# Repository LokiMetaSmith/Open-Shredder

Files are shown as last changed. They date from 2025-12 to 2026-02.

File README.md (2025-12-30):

# Open-Shredder
OpenShredder is a general purpose 3D printable shredder designed for recycling plastic

The goal of this project is to democratize the knowledge and empower individuals to remove plastics from their community waste stream and transform them through the below described processes into long lived, durable goods that can again be recycled at the end of their usefulness. 

# Scope of Work

Initially, non-uniform plastic objects need to be mechanically broken down into a uniform format that can be processed into new products. This first process requires a shredder, which is a machine that mechanically breaks plastic down into uniform pieces of a desired size.

The shredder needs to be relatively quiet and be able to handle the recyclable plastic seen in modern society. 
| Plastic #  |Abbr. |Description |
|---|---|---|
| Recycle #1 | PET  | polyethylene terephthalate | 
| Recycle #2 | HDPE | polyethylene, high density | 
| Recycle #3 | PVC  | poly(vinyl chloride) | 
| Recycle #4 | LDPE | polyethylene, low density  | 
| Recycle #5 | PP | polypropylene | 

Plastics can have fillers, contamination, or be damaged from UV, thermal, or mechanical stress that change their initial properties. In these cases, mixing in additive plastics can help mitigate the damage and restore some of the materials initial properties. Additive plastics can be freshly manufactured plastic or plastics with complementary properties. We're investigating if https://docs.plasticscanner.com/ can be used to fill this need.

On the market, there are several commercial shredder options designed for dedicated spaces and high volume plastic shredding. Unfortunately, these machines and techniques do not meet the above goal of being usable by a single individual. A cooperative community recycling center would be ideal for one of these high volume machines.

The best documented and supported DIY plastic shredder would be the Precious Plastics Shredder. However, the current bill of materials (BOM) lists the price as $2,234.17, which is an amazing 5x lower price difference from commercial shredders and is competitive with equivalent commercial shredders from Asian markets. This doesn’t include labor and overhead plus reinvestment profits. 

# Objective

To realize a further reduction of price and complexity, a shredder designed from the ground up to be sustainable and accessible needs to be developed. By designing mechanical components capable of being made on a 3D printer, we potentially can use the very plastic material shredded in the creation of new shredders, as well as expand the list of useful machines buildable with a 3D printer. When considering a shredder built of plastic designed to shred plastic, we will both need to create a community, collaborate with an existing community, or reinvigorate an inactive community as it is unlikely that our initial efforts will be sufficient to solve low cost waste processing. Community activity can’t only be limited to technical work. Cultural and social norms around recycling need to be addressed and both trust and accountability need to be earned. We can leverage an Open Source Hardware project and a call to action, along with organizational resources such as documentation management, official builds, development resources, and coordination of efforts. 

Currently the design of the shredder is thought to be a single shaft shredder, which is a simple but robust design that uses a pusher lever to feed material against rotating knives along a single stationary blade. A screen acts as a filter to only let material of a certain shape through. These machines use low speed, high torque gearboxes to process a high variety of materials. 

To accomplish this with a 3D printed shredder, it is envisioned that the central shaft will be 3D printed and like with commercial units, steel or carbide inserts will make up the cutting knife edges, and plastic will provide backing and support. To provide high torque, a cycloidal gearbox will be coupled to the shaft on both sides to provide support and the required force. 

Future work includes using the shredded material in a variety of applications, some of which are demonstrated by Precious Plastics, such as building materials and consumer goods. A further goal would be to use the shredded plastic for 3D printing as either feed stock for a filament extruder or directly with a pellet extruder 3D printing head. 

# Project Outline

## Tools Used
SPEC will develop an easily installable web hosted Jupyter notebook and docker container that has all the tools nessisary to contribute to this project. 

CadQuery is a parametric 3D Computer Aided Design (CAD) language and software library, written in Python, that allows for expressive 3D designs to be modeled and assembeled virtually. 

CadQuery: https://github.com/CadQuery/cadquery

Jupyter-CadQuery, combines the utility of Jupyter notebooks, with 3D cad drawings produced with CadQuery. It also allows for live code and deploy environments, and many more features. 

Jupiter-CadQuery: https://github.com/bernhard-42/jupyter-cadquery

## Proof of Concept

  The first proof of concept, will utilize a fully parametrized 3D printed shredder drum

## First Release

## Rolling Release Schedule

## Production and Manufacturing

## Call for Collaboration: Open Problems

  The project would benefit from a mechanical engineer or an expert 3D modeler, as the component geometries are getting complex. Also, the prime power drive is non obvious. Most commercial shredders use high speed, low torque electric AC motors with a gear reduction mechanism, which both increase cost and are non-standard. A creative solution would utilize the impact resistance of certain plastics to incorporate a fly wheel impact driver mechanism to increase the total torque output of the device. It is believed that doing so will allow for an almost completely 3D printed shredder. 

# Motor Selection

After reviewing the project requirements for a home-friendly, quiet, and 3D-printable capable shredder, we have selected the **NEMA 34 Stepper Motor** as the prime mover.

### Reasons for Selection:
1.  **High Torque:** NEMA 34 motors offer significantly higher holding torque (often 4-12 Nm) compared to NEMA 23, which is crucial for shredding solid chunks of plastic.
2.  **Quiet Operation:** Unlike universal AC motors or gearbox-driven DC motors, stepper motors run relatively quietly, making them suitable for home environments.
3.  **Direct Compatibility with Printed Gearbox:** The low speed of the stepper (typically <1000 RPM useful range) matches well with a single-stage cycloidal reduction (10:1 to 20:1) without requiring complex multi-stage gearing.
4.  **Future Proofing:** The NEMA 34 mounting standard is a common target for "3D Printed Brushless Motor" projects. By designing the gearbox for a NEMA 34 interface, this shredder can easily be upgraded to a DIY printable motor in the future.

### Configuration
- **Mounting Hole Spacing:** 69.6 mm
- **Shaft Diameter:** 14.0 mm
- **Driver:** A high-voltage (AC powered or 60V+ DC) stepper driver (e.g., DM860T) is recommended to maximize torque at speed.

### Alternative Option: Windshield Wiper Motor
For a low-cost, high-torque salvage option, the gearbox also supports a **Generic Wiper Motor** pattern.
- **Mounting:** 3-Bolt pattern (approx 2" / 50.8mm bolt circle).
- **Configuration:** Set `motor_type="WIPER"` in the assembly script.
- **Note:** Requires a high-current 12V DC power supply (e.g., PC PSU or Car Battery). Mounting holes may need slotting for specific motor variations.

# Cycloidal Generators:
https://github.com/RepRapLtd/RobotComponents/tree/main/RRL-cycloidal-drive
https://github.com/mawildoer/cycloidal_generator
https://github.com/mikedh/cycloidal
https://hackaday.io/project/168498-opencyre

## Related Projects
https://github.com/CubeFactory2/cubefactory
https://plasticscanner.com/

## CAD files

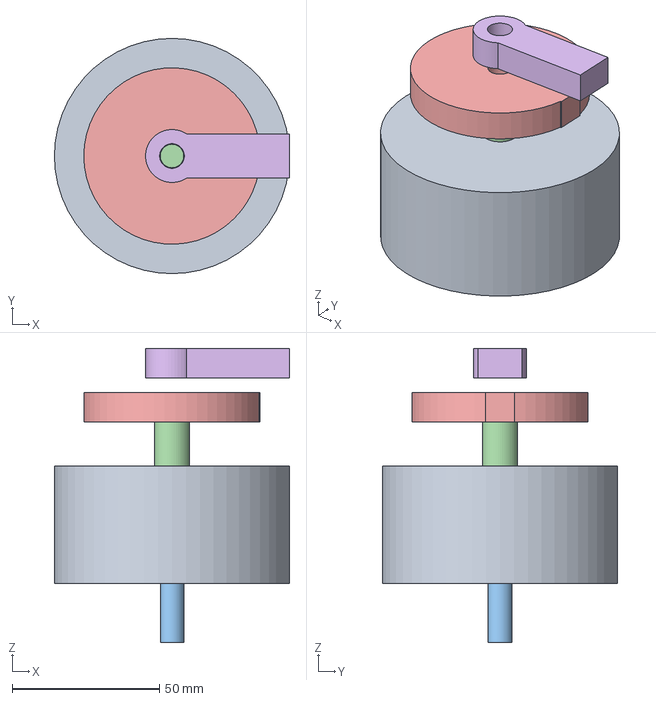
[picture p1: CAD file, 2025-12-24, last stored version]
shredder_gearbox_assembly.step
80.0 x 80.0 x 100.0 mm

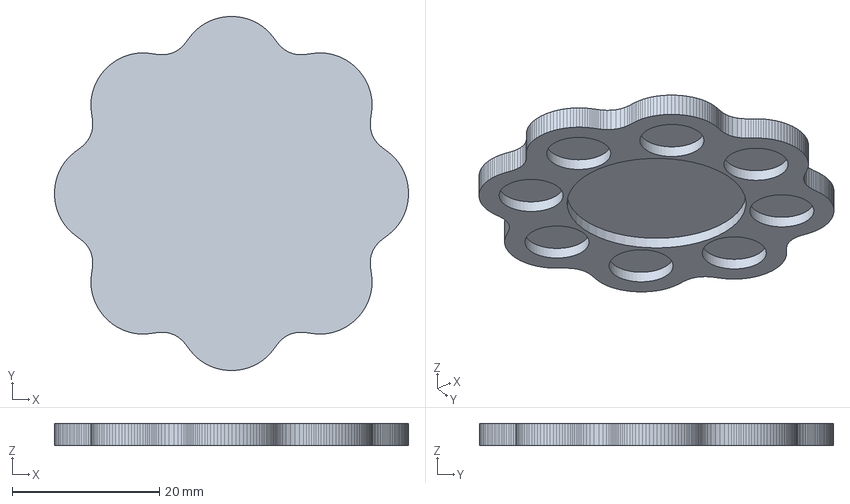
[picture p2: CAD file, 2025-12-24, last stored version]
cycloidal_disk.step
48.0 x 48.0 x 3.00 mm

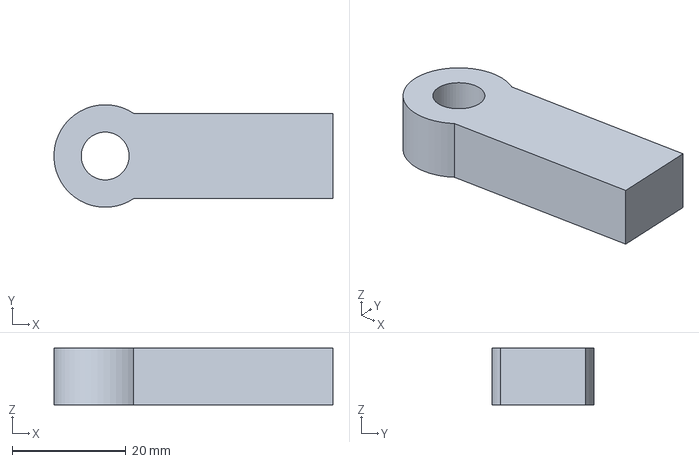
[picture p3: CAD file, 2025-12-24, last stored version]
impact_hammer.step
49.0 x 18.0 x 10.0 mm

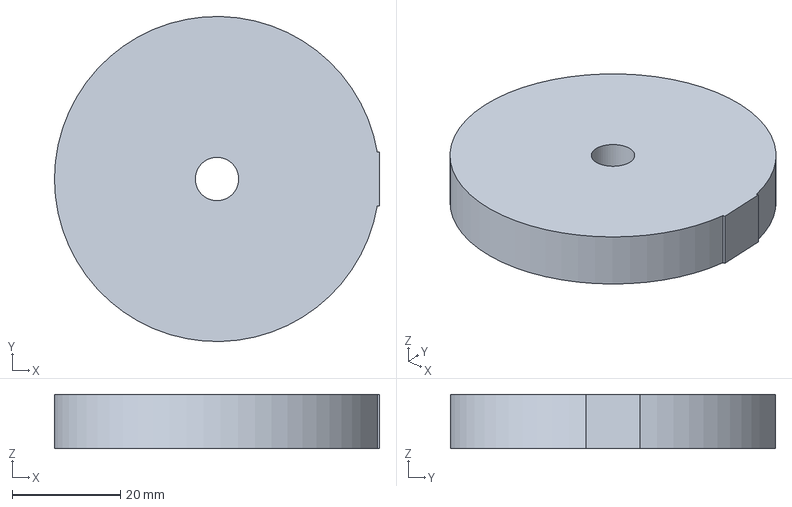
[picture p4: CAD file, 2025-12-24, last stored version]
slip_disk.step
60.0 x 60.0 x 10.0 mm

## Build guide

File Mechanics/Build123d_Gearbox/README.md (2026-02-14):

# OpenShredder Gearbox & Components (Build123d)

This directory contains Python scripts to generate the 3D models for the OpenShredder gearbox and shredder mechanism using [build123d](https://github.com/gumyr/build123d).

## Prerequisites

You need `build123d` and `scikit-fem` installed:
```bash
pip install build123d scikit-fem meshio numpy scipy
```

## Parameter Configuration

All design parameters are centralized in `parameters/shredder_config.json`.
You can modify this file directly, or use the Optimization Agent to tune it.

## New Workflow: Validation & Optimization

We have implemented an AI-driven optimization loop to ensure the design is mechanically sound.

### 1. Validate Design
Checks geometric constraints (e.g., shaft fit) and mechanical feasibility (torque).
```bash
python3 validate_design.py
```

### 2. Simulate Stress
Runs a Finite Element Analysis (FEA) or analytical simulation to calculate shaft stress and safety factors.
```bash
python3 simulate_stress.py
```

### 3. Optimize Design (Agent)
An intelligent agent that iteratively tweaks parameters (Gear Ratio, Shaft Size, Drum Diameter) to maximize throughput while satisfying safety constraints.
```bash
python3 optimize_design.py
```
This will generate `parameters/optimized_shredder_config.json`.

## Generating Models

The generation scripts automatically load `parameters/optimized_shredder_config.json` if it exists, otherwise they use `parameters/shredder_config.json`.

### Full Assembly
Generates the complete machine model (Gearbox + Shredder + Pusher).
```bash
python3 full_machine_assembly.py
```
- Output: `open_shredder_full_assembly.step`

### Individual Components

- **Gearbox:** `python3 gearbox_assembly.py` -> `shredder_gearbox_assembly.step`
- **Shredder Parts:** `python3 shredder_components.py`
- **Pusher:** `python3 pusher_mechanism.py`

## Scripts Overview

- `parameters/shredder_config.py`: Configuration schema.
- `validate_design.py`: Validation logic.
- `simulate_stress.py`: FEA/Analytical simulation logic.
- `optimize_design.py`: Optimization agent.
- `cycloidal_gear.py`: Generates the core cycloidal disk.
- `impact_drive.py`: Generates the slip-disk and impact hammer mechanism.
- `shredder_components.py`: Generates internal shredder parts.
- `gearbox_assembly.py`: Generates gearbox assembly.
- `full_machine_assembly.py`: Generates full machine assembly.

## Configuration
Adjust parameters in `parameters/shredder_config.json` manually or use `optimize_design.py`.

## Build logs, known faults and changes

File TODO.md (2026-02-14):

# OpenShredder Project Roadmap

This document tracks the ongoing development, optimization, and future feature requests for the OpenShredder project.

## 1. Mechanical Design (Build123d)

### Completed
- [x] **Parametric Gearbox:** Centralized configuration (`shredder_config.json`) for gear ratio, housing dimensions, and shaft sizes.
- [x] **End-to-End Validation:** Script (`validate_design.py`) to check geometric fit and torque requirements.
- [x] **Stress Simulation:** FEA-based torsion simulation (`simulate_stress.py`) for the hexagonal output shaft.
- [x] **Design Optimization Agent:** Automated script (`optimize_design.py`) to tune parameters for maximum throughput/safety.
- [x] **Full Assembly Generation:** `full_machine_assembly.py` generates the complete machine STEP file based on the optimized config.

### In Progress / TODO
- [ ] **Hopper Design:** The current `pusher_mechanism.py` is a placeholder. A full hopper with guide rails is needed.
- [ ] **Bearing Integration:** Explicitly model bearing pockets and select standard bearings (e.g., 6000 series) in the configuration.
- [ ] **Helical Gear Profile:** The current cycloidal drive uses straight pins. Evaluate helical or double-cycloid for smoother operation/noise reduction.
- [ ] **Fastener Library:** Add bolts, nuts, and washers to the assembly script for a complete BOM.
- [ ] **Frame/Stand:** Design a parametric frame (aluminum extrusion or welded steel) to mount the gearbox and motor.

## 2. Simulation & Analysis

### Completed
- [x] **Torsion FEA:** 2D Poisson solver for hexagonal shaft torsion.

### In Progress / TODO
- [ ] **Bending Moment Analysis:** The shaft also experiences bending from the shredding force. Update `simulate_stress.py` to include bending + torsion (Von Mises stress).
- [ ] **Tooth Strength Analysis:** Simulate the stress on the shredder teeth/inserts to prevent fracture.
- [ ] **Jamming Simulation:** Create a dynamic simulation (time-stepped) to model potential jam scenarios and test the "Impact Drive" effectiveness.
- [ ] **Thermal Analysis:** Estimate heat generation in the gearbox/motor for continuous duty cycles.

## 3. Firmware (Arduino Motor Controller)

### Completed
- [x] **Basic Motor Control:** Stepper and DC motor support.
- [x] **Jam Detection:** Current monitoring and auto-reverse logic.

### In Progress / TODO
- [ ] **Load-Dependent Speed Control:** Automatically reduce speed (increase torque) when current spikes, before a full jam occurs.
- [ ] **Impact Mode Tuning:** Refine the "back-off and strike" algorithm parameters based on real-world testing.
- [ ] **User Interface:** Add a simple LCD/OLED menu to configure settings (e.g., reverse time, current limit) without reflashing.
- [ ] **Telemetry:** Output real-time current/RPM data to serial for analysis/digital twin verification.

## 4. Documentation

### Completed
- [x] **Workflow Documentation:** Updated `Mechanics/Build123d_Gearbox/README.md` with new validation/optimization steps.

### In Progress / TODO
- [ ] **Assembly Manual:** Step-by-step PDF or Wiki for assembling the physical hardware.
- [x] **Bill of Materials (BOM):** Auto-generate a CSV BOM from the python scripts (`generate_bom.py`).
- [ ] **Tuning Guide:** Instructions on how to interpret validation errors and manually tune the `shredder_config.json`.

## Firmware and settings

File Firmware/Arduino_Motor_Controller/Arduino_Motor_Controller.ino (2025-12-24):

#include "DCDriver.h"
#include "StepperDriver.h"
#include "ShredderController.h"

// ================= USER CONFIGURATION =================

// Select Motor Type: 1 = DC, 2 = STEPPER
#define MOTOR_TYPE 1

// --- Pins for DC Motor ---
#define PIN_DC_PWM      3
#define PIN_DC_DIR      4
#define PIN_DC_CURRENT  A0

// --- Pins for Stepper Motor ---
#define PIN_STEP_PUL    3
#define PIN_STEP_DIR    4
#define PIN_STEP_ENA    5
#define PIN_STEP_ALARM  6

// --- Logic Settings ---
#define CURRENT_LIMIT   800   // 0-1023 ADC
#define USE_IMPACT_MODE true  // Enable Impact Hammer logic

// ======================================================

MotorInterface* driver = nullptr;
ShredderController* controller = nullptr;

void setup() {
    Serial.begin(115200);
    Serial.println("Shredder Controller Starting...");

    // Initialize Driver
    #if MOTOR_TYPE == 1
        driver = new DCDriver(PIN_DC_PWM, PIN_DC_DIR, PIN_DC_CURRENT);
        Serial.println("Mode: DC Motor");
    #elif MOTOR_TYPE == 2
        driver = new StepperDriver(PIN_STEP_PUL, PIN_STEP_DIR, PIN_STEP_ENA, PIN_STEP_ALARM);
        Serial.println("Mode: Stepper Motor");
    #endif

    driver->begin();

    // Initialize Controller
    controller = new ShredderController(driver);

    ShredderConfig config;
    config.forwardSpeed = 100; // 100%
    config.reverseSpeed = 60;
    config.currentLimit = CURRENT_LIMIT;
    config.runDuration = 0; // Infinite
    config.useImpactMode = USE_IMPACT_MODE;

    controller->setConfig(config);

    // Start Sequence
    controller->start();
    Serial.println("Controller Started.");
}

void loop() {
    // Main update loop
    if (controller) {
        controller->update();

        // Optional: Print Status periodically
        static unsigned long lastPrint = 0;
        if (millis() - lastPrint > 1000) {
            lastPrint = millis();
            Serial.print("State: ");
            Serial.print(controller->getState());
            Serial.print(" Load: ");
            Serial.println(driver->getLoad());
        }
    }
}

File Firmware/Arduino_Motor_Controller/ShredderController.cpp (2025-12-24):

#include "ShredderController.h"

#ifdef ARDUINO
    #include <Arduino.h>
#else
    #include "../tests/mock_arduino.h"
#endif

ShredderController::ShredderController(MotorInterface* motor) {
    _motor = motor;
    _state = STATE_IDLE;
    _jamCount = 0;

    // Defaults
    _config.forwardSpeed = 100;
    _config.reverseSpeed = 50;
    _config.currentLimit = 800;
    _config.runDuration = 0;
    _config.reverseDuration = 2000;
    _config.useImpactMode = false;
    _config.impactBackoffDuration = 1000;
}

void ShredderController::setConfig(ShredderConfig config) {
    _config = config;
}

void ShredderController::start() {
    _state = STATE_FORWARD;
    _stateStartTime = millis();
    _runStartTime = millis();
    _motor->setSpeed(_config.forwardSpeed);
    _jamCount = 0;
}

void ShredderController::stop() {
    _state = STATE_IDLE;
    _motor->stop();
}

void ShredderController::update() {
    unsigned long now = millis();
    _motor->update(); // Tick the motor driver

    // State Machine
    switch (_state) {
        case STATE_IDLE:
            // Do nothing
            break;

        case STATE_FORWARD:
            // Check Timeout
            if (_config.runDuration > 0 && (now - _runStartTime > _config.runDuration)) {
                stop();
                return;
            }

            // Inrush Masking: Ignore current spikes during the first 500ms of entering STATE_FORWARD
            if (now - _stateStartTime > 500) {
                // Check Jam/Fault
                if (_motor->getLoad() > _config.currentLimit || _motor->isFaulted()) {
                    _state = STATE_JAM_DETECTED;
                    _stateStartTime = now;
                    _motor->stop();
                    _jamCount++;
                }
            }
            break;

        case STATE_JAM_DETECTED:
            // Pause briefly before reversing to protect electronics
            if (now - _stateStartTime > 500) {
                if (_config.useImpactMode) {
                    // Impact Strategy: Back up, then strike
                    _state = STATE_IMPACT_PREP_BACKOFF;
                    _motor->setSpeed(-_config.reverseSpeed);
                } else {
                    // Standard Strategy: Reverse, then Forward
                    _state = STATE_REVERSE_CLEARING;
                    _motor->setSpeed(-_config.reverseSpeed);
                }
                _stateStartTime = now;
            }
            break;

        case STATE_REVERSE_CLEARING:
            if (now - _stateStartTime > _config.reverseDuration) {
                _state = STATE_FORWARD;
                _motor->setSpeed(_config.forwardSpeed);
                _stateStartTime = now;
            }
            break;

        case STATE_IMPACT_PREP_BACKOFF:
            // Back up significantly
            if (now - _stateStartTime > _config.impactBackoffDuration) {
                _state = STATE_IMPACT_STRIKE;
                // Full speed forward for maximum inertia
                _motor->setSpeed(100);
                _stateStartTime = now;
            }
            break;

        case STATE_IMPACT_STRIKE:
            // We stay in this mode for a minimum time to ensure we hit the object
            // or we just switch back to FORWARD monitoring immediately?
            // Let's switch to FORWARD after a brief acceleration period
            if (now - _stateStartTime > 500) {
                _state = STATE_FORWARD;
                _motor->setSpeed(_config.forwardSpeed);
                _stateStartTime = now;
            }
            break;

        case STATE_PAUSED:
            // Placeholder
            break;
    }
}

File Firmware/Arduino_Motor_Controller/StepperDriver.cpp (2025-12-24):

#include "StepperDriver.h"

StepperDriver::StepperDriver(uint8_t pinStep, uint8_t pinDir, uint8_t pinEnable, uint8_t pinAlarm) {
    _pinStep = pinStep;
    _pinDir = pinDir;
    _pinEnable = pinEnable;
    _pinAlarm = pinAlarm;
    _currentSpeed = 0;
    _stepIntervalMicros = 0;
    _lastStepTime = 0;
    _stepState = false;
    _enabled = false;
}

void StepperDriver::begin() {
    pinMode(_pinStep, OUTPUT);
    pinMode(_pinDir, OUTPUT);
    pinMode(_pinEnable, OUTPUT);
    digitalWrite(_pinEnable, HIGH); // Disable by default (High Impedance)

    if (_pinAlarm != 255) {
        pinMode(_pinAlarm, INPUT_PULLUP);
    }
}

void StepperDriver::setSpeed(int speed_percent) {
    _currentSpeed = speed_percent;

    if (_currentSpeed == 0) {
        stop();
        return;
    }

    // Enable Driver
    if (!_enabled) {
        digitalWrite(_pinEnable, LOW); // Enable (Active Low common)
        _enabled = true;
    }

    // Set Direction
    if (_currentSpeed > 0) {
        digitalWrite(_pinDir, HIGH);
    } else {
        digitalWrite(_pinDir, LOW);
    }

    // Calculate Interval
    // Max Speed: Let's assume 100% = 2000 steps/sec (just an example base)
    // 2000 steps/sec -> 500us period -> 250us toggle
    // 1% = 20 steps/sec -> 50000us period
    // Simple Mapping: Map 1-100 to 10000us - 200us

    int absSpeed = abs(_currentSpeed);
    if (absSpeed > 100) absSpeed = 100;

    // Non-linear mapping is often better but linear for now
    // Interval = 10000 - (speed * 98) ?
    // Speed 1: 10000 - 98 = 9902us -> 100Hz
    // Speed 100: 10000 - 9800 = 200us -> 5kHz
    _stepIntervalMicros = map(absSpeed, 1, 100, 10000, 200);
}

void StepperDriver::stop() {
    _currentSpeed = 0;
    _enabled = false;
    digitalWrite(_pinEnable, HIGH); // Disable
}

void StepperDriver::update() {
    if (!_enabled || _currentSpeed == 0) return;

    unsigned long now = micros();
    if (now - _lastStepTime >= _stepIntervalMicros) {
        _lastStepTime = now;
        _stepState = !_stepState;
        digitalWrite(_pinStep, _stepState ? HIGH : LOW);
    }
}

int StepperDriver::getLoad() {
    // Steppers don't provide load unless via external sensor.
    // If we have an alarm, we return MAX_LOAD if alarmed.
    if (isFaulted()) return 1023; // Max simulated load
    return 0;
}

bool StepperDriver::isFaulted() {
    if (_pinAlarm != 255) {
        // Assume Active LOW alarm or Active HIGH depending on driver.
        // Often Open Collector -> Pullup -> LOW means Alarm.
        // But Leadshine is configurable. Let's assume LOW is Alarm.
        // Actually, let's assume HIGH is Alarm for generic safety?
        // Let's stick to standard input pullup: LOW = Active Alarm usually.
        return digitalRead(_pinAlarm) == LOW;
    }
    return false;
}

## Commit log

2025-12-24 Add scriptable motor driver firmware for OpenShredder
    - Implemented `MotorInterface` abstraction for polymorphic motor support.
    - Added `DCDriver` for PWM/Direction based DC motor control with current sensing.
    - Added `StepperDriver` for Step/Direction/Enable stepper control with alarm support.
    - Implemented `ShredderController` state machine:
    - Handles Normal Run, Jam Detection, and Reverse Clearing.
    - Implemented configurable "Impact Mode" (Backoff + Strike) strategy.
    - Added `Arduino_Motor_Controller.ino` main sketch with user configuration section.
    - Added `tests/` with mock Arduino environment for logic verification.
    - Verified logic with `test_main.cpp`.
    [Arduino_Motor_Controller.ino, DCDriver.cpp, ShredderController.cpp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]
2025-12-24 Add Arduino motor controller and build123d gearbox models
    - Added `Firmware/Arduino_Motor_Controller/` with C++ firmware for DC and Stepper motors.
    - Implemented `ShredderController` with Jam Detection and Impact Mode logic.
    - Added `Firmware/tests/` with mock Arduino environment and unit tests.
    - Added `Mechanics/Build123d_Gearbox/` containing Python scripts for parametric 3D modeling.
    - Implemented `cycloidal_gear.py`, `impact_drive.py`, and `gearbox_assembly.py` using `build123d`.
    - Generated STEP files for the gearbox and impact mechanism.
    [cycloidal_disk.step, impact_hammer.step, shredder_gearbox_assembly.step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]
2025-12-24 Add Arduino motor controller and build123d gearbox models
    - Implemented Inrush Current Masking to prevent false jams on startup.
    - Implemented `cycloidal_gear.py`, `impact_drive.py`, `gearbox_assembly.py` using `build123d`.
    - Added `shredder_components.py` for drum and insert modeling.
    - Added `full_machine_assembly.py` generating the complete shredder.
    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
    [cycloidal_disk.step, impact_hammer.step, shredder_gearbox_assembly.step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]
2025-12-30 Feat: Update design for NEMA 34 Stepper Motor
    - Select NEMA 34 Stepper as the prime mover for high torque and quiet operation.
    - Update `gearbox_assembly.py` to support NEMA 34 dimensions (69.6mm spacing, 14mm shaft, 100mm housing).
    - Update `full_machine_assembly.py` to use the NEMA 34 configuration.
    - Update `README.md` with motor selection justification.
2025-12-30 Feat: Add Windshield Wiper Motor and NEMA 34 Options
    - Update `gearbox_assembly.py` to support `motor_type="NEMA34"` and `motor_type="WIPER"`.
    - Implement parametric housing sizing:
    - NEMA 34: 120mm OD, 69.6mm grid spacing, 14mm shaft.
    - WIPER: 120mm OD, 50.8mm polar spacing (3-bolt), 10mm shaft.
    - Update `full_machine_assembly.py` to use NEMA 34 as default.
    - Update `README.md` to document the new motor options.
    - Fix geometric issue where 100mm housing was too small for NEMA 34 mounting holes.
2026-02-14 Implement parametric design, validation, and optimization for the OpenShredder gearbox
    - Centralized design parameters in `Mechanics/Build123d_Gearbox/parameters/shredder_config.py`.
    - Refactored `gearbox_assembly.py`, `shredder_components.py`, `full_machine_assembly.py` to use configuration.
    - Added `validate_design.py` to check geometric and mechanical constraints (torque, fit).
    - Added `simulate_stress.py` to perform FEA (via `scikit-fem`) or analytical stress analysis on the output shaft.
    - Added `optimize_design.py`, an agent that iteratively tunes parameters to maximize throughput while satisfying safety factors.
    - Updated `README.md` with instructions for the new workflow.
    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
2026-02-14 Implement parametric design, validation, and optimization for the OpenShredder gearbox
    - Added `TODO.md` to track future development.
    - Updated `README.md` with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
2026-02-14 Implement parametric design, validation, and optimization for the OpenShredder gearbox
    - Added `generate_bom.py` to calculate a Bill of Materials (BOM) based on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
2026-02-14 feat: add bearing configuration and pockets to gearbox assembly
    - Added `BearingConfig` to `shredder_config.py` with default 6006 bearing.
    - Updated `shredder_config.json` with the new bearing parameters.
    - Updated `gearbox_assembly.py` to:
    - Create a bearing pocket on the top face of the housing.
    - Create a matching bearing journal on the output shaft.
    - Add a visual representation of the bearing to the assembly.
2026-11-11 Harden firmware jam recovery and mechanical simulation
    - Add max jam retry limit and STATE_FAULTED to ShredderController
    to prevent hardware damage on unrecoverable jams.
    - Implement combined bending and torsional Von Mises stress
    simulation in simulate_stress.py.
    - Add robust CLI argument interfaces to validate_design.py,
    simulate_stress.py, optimize_design.py, and generate_bom.py.
    - Implement comprehensive unit tests for StepperDriver and
    fault handling in test_main.cpp.
    - Add pytest test suite in Mechanics/tests/test_mechanics.py
    verifying config I/O, validation rules, stress simulation,
    BOM generation, and deterministic optimization.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
2026-11-11 Implement firmware hardening, mechanical features and CAD improvements
    - Add jam retry limit, STATE_FAULTED, load-dependent dynamic speed derating,
    and serial telemetry output to ShredderController and Arduino sketch.
    - Implement combined bending and torsional Von Mises stress simulation in
    simulate_stress.py.
    - Model bearing pockets and assembly fastener libraries in parameters and
    gearbox_assembly.py.
    - Implement parametric hopper with guide rails and guided pusher block in
    pusher_mechanism.py.
    - Add tune_shredder.py CLI tool supporting polymer recyclables (PET, HDPE,
    PVC, LDPE, PP) and real-time safety factor calculations.
    - Implement unit tests covering StepperDriver, jam fault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
